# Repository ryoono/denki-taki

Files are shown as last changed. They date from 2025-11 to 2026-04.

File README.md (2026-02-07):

# denki-taki

## 要求仕様
[要求仕様](./docs/requirement.md)は別資料にまとめる。  

## ソフトウェア設計

```mermaid
flowchart TD
  %% =========================
  %% System Overview
  %% =========================
  subgraph SYS[Main loop control / non blocking]
    NOW[millis -> now]
    DOUT[D6 D7 pulse scheduler]
    CANDLE[LED flicker scheduler]
  end

  NOW --> DOUT
  NOW --> CANDLE

  %% =========================
  %% LED Flicker PWM D5 D9
  %% =========================
  subgraph PWM[LED flicker PWM on D5 D9]
    SCH[nextUpdateMs gate]
    FOLD[Folded quadratic mapping\nvalue update]
    EDGE[Edge re injection\nrandom reset near limits]
    PHASE[Opposite phase mapping\nvalue_1 value_2]
    CLAMP[Clamp 0 to 255]
    GAMMA[Gamma correction\ngamma8 table]
    WRITE[Write PWM duty\nwriteCh1 writeCh2]
    JIT[Jitter dt\nnextUpdateMs update]
  end

  CANDLE --> SCH
  SCH -->|now >= nextUpdateMs| FOLD
  FOLD --> EDGE
  EDGE --> PHASE
  PHASE --> CLAMP
  CLAMP --> GAMMA
  GAMMA --> WRITE
  WRITE --> JIT
  JIT --> SCH

  %% =========================
  %% Hardware PWM mapping
  %% =========================
  subgraph HW_PWM[Hardware PWM mapping]
    MAP[map255ToT1\n0 to 255 -> 0 to 999]
    D5[D5 Timer3 OC3A\nOCR3A]
    D9[D9 Timer1 OC1A\nOCR1A]
    TOP[T1_TOP = 999\nprescaler 8]
  end

  WRITE --> MAP
  MAP --> D5
  MAP --> D9
  TOP --> MAP

  %% =========================
  %% Digital output scheduling
  %% =========================
  subgraph DOUT_SM[D6 D7 digital pulse control]
    RND[randWaitMs\n500 to 10000 ms]
    D6SM[D6 state machine]
    D7SM[D7 state machine\nblock overlap]
  end

  DOUT --> DOUT_SM
  RND --> D6SM
  RND --> D7SM

  %% D6 state machine
  subgraph D6STATE[D6 state]
    D6WAIT[WAIT\nnow < d6NextMs]
    D6ON[ON 40 ms\nnow < d6OffMs]
    D6OFF[OFF\nschedule next]
  end

  D6SM --> D6WAIT
  D6WAIT -->|timeout| D6ON
  D6ON -->|40 ms elapsed| D6OFF
  D6OFF -->|set next wait| D6WAIT

  %% D7 state machine
  subgraph D7STATE[D7 state]
    D7WAIT[WAIT\nnow < d7NextMs]
    D7CHECK[Check overlap\nwith D6]
    D7DEFER[Defer\nwait for D6 OFF]
    D7ON[ON 40 ms\nnow < d7OffMs]
    D7OFF[OFF\nschedule next]
  end

  D7SM --> D7WAIT
  D7WAIT -->|timeout| D7CHECK
  D7CHECK -->|D6 ON| D7DEFER
  D7DEFER --> D7WAIT
  D7CHECK -->|D6 OFF| D7ON
  D7ON -->|40 ms elapsed| D7OFF
  D7OFF -->|set next wait| D7WAIT

  %% =========================
  %% Pin usage summary
  %% =========================
  subgraph IO[Pin usage D2 to D9]
    P2[D2 free]
    P3[D3 free]
    P4[D4 free]
    P5[D5 PWM CH1]
    P6[D6 digital pulse]
    P7[D7 digital pulse blocked]
    P8[D8 free]
    P9[D9 PWM CH2]
  end

  D6ON --> P6
  D7ON --> P7
  D5 --> P5
  D9 --> P9
```

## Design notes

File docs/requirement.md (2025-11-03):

本資料は「電気TAKI-焚-」要求仕様に関してまとめる。  

# 🔥 電気焚火キャンドル ― 設計思想（要約）

焚き火の魅力は「同じ瞬間が二度とない」こと。  
本作品はその偶然性と癒しを、電子制御ではなく**物理現象**によって再現する。  
ソレノイドが実際に空気を震わせ、吊り板が微妙に揺らぐ。  
その**わずかな誤差や乱れ**が、電子機器に“一期一会”の**わびさび**を与える。  
焚き火や焚き火キャンドルは火を用いるため扱いに注意が必要だが、本デバイスは電気で動作するため、安全性が高い。  

# 🔥 5W1H概要

| 要素 | 内容 |
|---|---|
| **Who（誰が）** | 室内で火を使えない人々（マンション・学生寮・家庭内など）や、就寝前に落ち着いた時間を過ごしたい人。 |
| **What（何を）** | 焚き火キャンドルのような**穏やかな炎の光と“パチパチ音”**を、火を使わずに再現する**リラックス用インテリアデバイス**。LEDの炎表現と、ソレノイドによる物理音が組み合わされた“電気焚火”。 |
| **When（いつ）** | 就寝前や読書・休憩・瞑想時など、**静かな夜のリラックスタイム**。長時間の点灯や寝落ちも想定し、安全性を重視。 |
| **Where（どこで）** | **室内（寝室・書斎・リビング）** など、火気厳禁かつ静音性を求める空間。小型設計で机上・ベッドサイドなどに設置可能。 |
| **Why（なぜ）** | 既製の電気焚火は「スピーカーからの擬似音が人工的」という課題がある。<br>本作品では、**ソレノイドが物理的に音を鳴らす**ことで、より**自然で偶然性のある“生きた音”**を再現する。<br>火の危険を排除し、現代生活に適した“安全な焚き火体験”を提供する。 |
| **How（どのように）** | - **LEDの揺らぎ**で炎を再現（オレンジ＋温白、帽子型拡散カバーで柔らかい光）<br>- **吊り板（木製・プラスチック製）をソレノイドで叩く**ことで“パチッ”“コツッ”と自然な破裂音を生成<br>- 板が揺れるたびに**当たり所が変わるため、同じ音は二度と鳴らない**<br>- 熱や煙を出さず、**安全で長時間使用可能**<br>- **ネットワーク接続機能**を持ち、Webページ経由で設定を行う（物理ボタンを排除） |

# 🔥 要求仕様書

## 1. 機能要求（Functional Requirements）

| ID | 要求項目 | 要求内容 |
|----|---|---|
| FR-1 | 炎の表現機能 | LEDの明滅により、焚き火キャンドルの炎を模した**穏やかな光のゆらぎ**を表現する。光源は複数色LED（オレンジ・温白など）を用いる。 |
| FR-2 | 音の生成機能 | ソレノイドの機械的打撃によって、焚き火の「パチッ」「コツッ」という**物理的な破裂音**を生成する。スピーカーは使用しない。 |
| FR-3 | ランダム性の再現 | 吊り板（木・プラスチック）が揺れ、**打撃の当たり所が毎回異なる**ように設計する。電子的なノイズ生成ではなく、機械的偶然性で音の多様性を生む。 |
| FR-4 | 光と音の調和 | LEDのゆらぎとソレノイドの発音が**全体として焚き火のテンポ感**を再現する。不自然な連打や長無音が発生しない。 |
| FR-5 | 安全動作 | 火災・感電・過熱などの危険がない構造とし、安全な低電圧電源で動作する。 |
| FR-6 | 操作性 | 本体に複数の物理スイッチを設けず、**最小限の電源スイッチまたは無操作起動**を基本とする。 |
| FR-7 | 自動停止機能 | 一定時間後に自動消灯・休止を行い、寝落ち時でも安全に使用できる。 |
| FR-8 | ネットワーク設定・制御機能 | 自宅のネットワークに接続し、**Webブラウザから設定や操作ができる**こと。<br>・自動停止時間や光の明るさをWebページ上で変更可能。<br>・Wi-Fi設定はプログラム直書きでよい。<br>・本体外観のスタイリッシュさを優先するため、ボタンや表示を極力省略する。 |

---

## 2. 非機能要求（Non-Functional Requirements）

| ID | 要求項目 | 要求内容 |
|----|---|---|
| NFR-1 | 静音性 | 音は就寝環境で心地よく感じられる程度とし、不快なノイズや過大な衝撃音を発生させない。 |
| NFR-2 | 音質 | 音は乾いた破裂音として自然に聴こえること。余韻やこもりを感じさせないこと。 |
| NFR-3 | 光の質感 | LED光は柔らかく、直視しても眩しくない。帽子型拡散カバーで穏やかに。 |
| NFR-4 | 審美性 | **ボタンや表示を極力排除**し、シンプルで静かな外観とする。配線は背面にまとめ、生活空間に溶け込むデザインとする。 |
| NFR-5 | 耐久性 | 通常の使用環境下で、打撃や吊り構造の破損・絡みが生じない。 |
| NFR-6 | メンテナンス性 | 構造を簡素にし、吊り板・糸・チップなどの交換を容易に行える。 |
| NFR-7 | 信頼性 | 長時間運転しても誤作動や過熱が発生しない。 |
| NFR-8 | 感性価値 | 同じ音が二度と鳴らない「偶然性」を体験価値として設計に組み込む。 |
| NFR-9 | ネットワーク操作性 | 設定画面はスマートフォンやPCのブラウザから簡単に操作できること。特別なアプリを不要とし、操作の反応が快適であること。 |

---

## 3. 制約条件（Constraints）

| ID | 制約項目 | 内容 |
|----|---|---|
| C-1 | 火気・煙 | 火炎・煙・香料などを一切発生させない。 |
| C-2 | 電源 | **安全な低電圧電源**で動作させる。給電方式（AC / DC / USB等）は問わない。 |
| C-3 | 筐体寸法 | デスクやベッドサイドに設置可能な小型サイズとする。 |
| C-4 | 環境条件 | 一般的な室内環境で安定して動作すること。 |
| C-5 | 騒音制限 | ソレノイドの駆動音や筐体の共振が不快にならないよう防振構造を採用する。 |
| C-6 | 安全規格 | ショート・逆接・過熱・絶縁不良が起きない構造とする。 |
| C-7 | 製作制約 | 入手容易な電子部品・素材を使用し、特殊加工を必要としない。 |
| C-8 | ネットワーク | ネットワーク設定値（SSID・パスワード）はプログラム内に固定で保持する。通信は家庭内ネットワーク内で完結する。 |

---

## 4. プロジェクト条件（Project Conditions）

| 項目 | 内容 |
|---|---|
| 開発目的 | **第13回ソレコン（タカハソレノイドコンテスト）** への出展。<br>「癒し × ソレノイド × 電気表現」をテーマとした作品として提出。 |
| 納期 | **2026年2月16日（月）までにデバイス完成および提出動画の作成・提出を完了する。** |
| マイルストーン | <br>**2025年12月中**：ハードウェア設計・部品選定完了。<br>**2026年1月中旬**：ソレノイド・LED動作試作完了。<br>**2026年1月末**：ネットワーク機能統合・筐体設計完了。<br>**2026年2月前半**：デモ撮影・編集・提出準備。 |
| 成果物 | - 動作デモ動画（作品紹介＋構造説明）<br>- 実機（展示用）<br>- 本要求仕様書（GitHubにて公開・管理） |

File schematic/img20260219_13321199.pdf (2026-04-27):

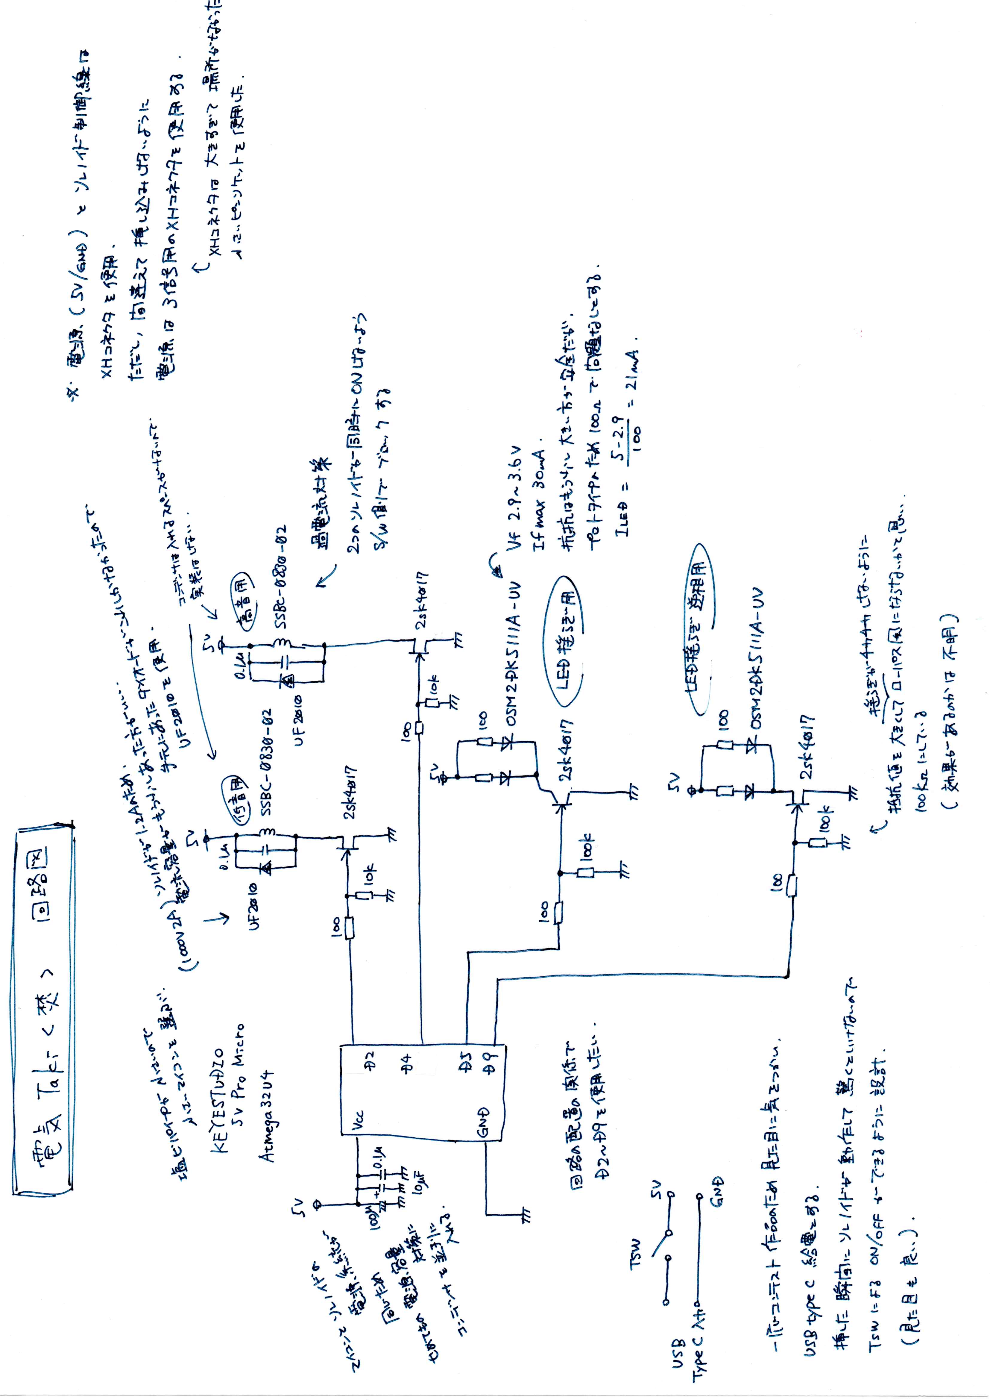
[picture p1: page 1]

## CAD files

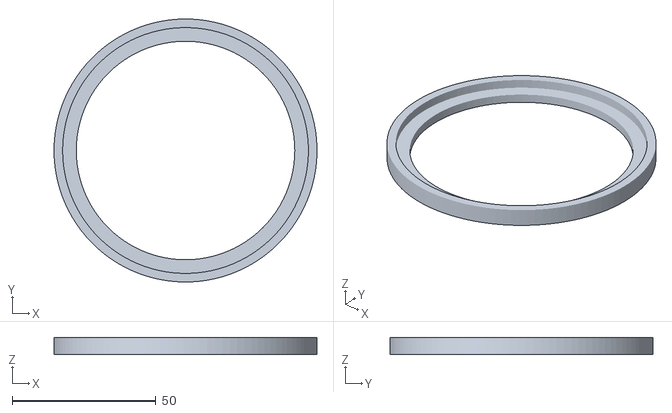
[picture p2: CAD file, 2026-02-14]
3d_data/キャンドルカバー.stl
91.5 x 91.5 x 6.00

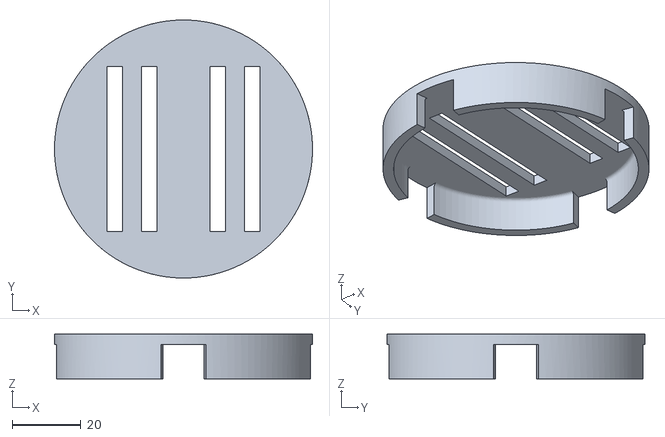
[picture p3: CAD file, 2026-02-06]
3d_data/ソレノイド固定台.stl
75.0 x 75.0 x 13.0

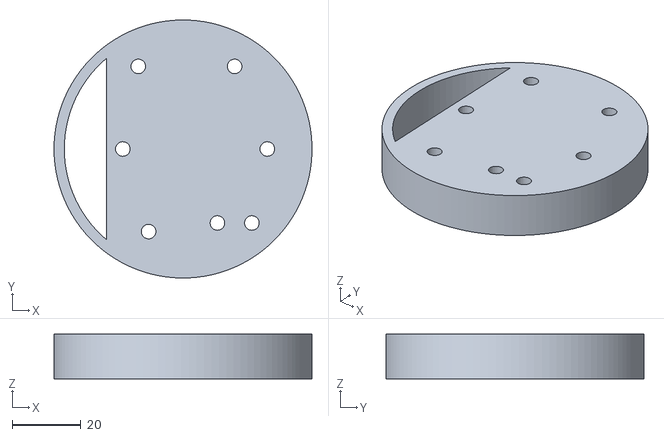
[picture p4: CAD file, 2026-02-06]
3d_data/マイコン固定台.stl
75.0 x 75.0 x 13.0

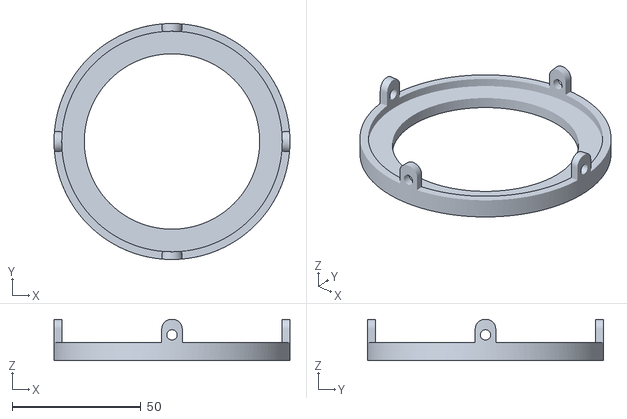
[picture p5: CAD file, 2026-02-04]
3d_data/塩ビパイプ_土台.stl
91.5 x 91.5 x 16.0

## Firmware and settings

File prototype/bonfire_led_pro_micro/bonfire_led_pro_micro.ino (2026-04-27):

/*
 * ボード：Amazonで購入した「KEYESTUDIO 5V Pro Micro Atmega32U4」
 * コンパイル時のボード設定：Arduino Leonardo
 * 
 * LEDの揺らぎ表現は、以下のWeb記事で紹介されている手法を元に実装している。
 * アルゴリズム自体はオリジナルではなく、実装方法を参考にしている。
 * https://www.creativity-ape.com/entry/2020/12/16/232928
 * 
 * ソレノイドはランダム時間ごとに駆動する。
 * ただし、過電流を防ぐため片方ずつしか駆動しないようソフトウェアでブロックしている。
 * 
 * D5：
 *   LED揺らぎ用PWM出力（CH1）
 *   - Timer3 / OC3A
 *   - Fast PWM（TOP=999, prescaler=8）
 *   - gamma補正後のdutyを出力
 * 
 * D9：
 *   LED揺らぎ用PWM出力（CH2）
 *   - Timer1 / OC1A
 *   - Fast PWM（TOP=999, prescaler=8）
 *   - D5と逆位相の揺らぎ表現
 * 
 * D2：
 *   デジタル出力（パルス制御）破裂音担当
 *   - 0～30000msのランダム待ち時間後にON
 *   - ON時間は40ms固定
 *   - 過電流防止のため、D4と同時ONしない
 * 
 * D4：
 *   デジタル出力（パルス制御）折れ音担当
 *   - 0～20000msのランダム待ち時間後にON
 *   - ON時間は40ms固定
 *   - D2がON中の場合は、D2がOFFになるまでONを待機
*/

#include <Arduino.h>
#include <avr/pgmspace.h>

// ---- Gamma table ----
// 人間の目の明るさ感覚に合わせるための gamma 補正テーブル
// 0–255 の duty 値を、見た目が自然になるように変換する
const uint8_t PROGMEM gamma8[] = {
  0, 0, 0, 0, 0, 0, 0, 0, 0, 0, 0, 0, 0, 0, 0, 0,
  0, 0, 0, 0, 0, 0, 0, 0, 0, 0, 0, 0, 1, 1, 1, 1,
  1, 1, 1, 1, 1, 1, 1, 1, 1, 2, 2, 2, 2, 2, 2, 2,
  2, 3, 3, 3, 3, 3, 3, 3, 4, 4, 4, 4, 4, 5, 5, 5,
  5, 6, 6, 6, 6, 7, 7, 7, 7, 8, 8, 8, 9, 9, 9, 10,
  10, 10, 11, 11, 11, 12, 12, 13, 13, 13, 14, 14, 15, 15, 16, 16,
  17, 17, 18, 18, 19, 19, 20, 20, 21, 21, 22, 22, 23, 24, 24, 25,
  25, 26, 27, 27, 28, 29, 29, 30, 31, 32, 32, 33, 34, 35, 35, 36,
  37, 38, 39, 39, 40, 41, 42, 43, 44, 45, 46, 47, 48, 49, 50, 50,
  51, 52, 54, 55, 56, 57, 58, 59, 60, 61, 62, 63, 64, 66, 67, 68,
  69, 70, 72, 73, 74, 75, 77, 78, 79, 81, 82, 83, 85, 86, 87, 89,
  90, 92, 93, 95, 96, 98, 99, 101, 102, 104, 105, 107, 109, 110, 112, 114,
  115, 117, 119, 120, 122, 124, 126, 127, 129, 131, 133, 135, 137, 138, 140, 142,
  144, 146, 148, 150, 152, 154, 156, 158, 160, 162, 164, 167, 169, 171, 173, 175,
  177, 180, 182, 184, 186, 189, 191, 193, 196, 198, 200, 203, 205, 208, 210, 213,
  215, 218, 220, 223, 225, 228, 231, 233, 236, 239, 241, 244, 247, 249, 252, 255
};

// ---- PWM pins ----
// PWM出力に使用するピン
// D5 : Timer3 / OC3A
// D9 : Timer1 / OC1A
static const uint8_t LED_PIN_1 = 5; // D5  (Timer3 OC3A)
static const uint8_t LED_PIN_2 = 9; // D9  (Timer1 OC1A)

// ---- Digital output pins ----
// 単純な digital output 用ピン（PWMは使わない）
static const uint8_t DOUT_PIN_2 = 2; // D2
static const uint8_t DOUT_PIN_4 = 4; // D4

// ---- Digital output timing parameters ----
// デジタル出力のON時間と待ち時間の条件
static const uint16_t DOUT_ON_MS        = 20;     // ONする時間 [ms]
static const uint16_t DOUT_WAIT_MINMS   = 500;    // 待ち時間の最小値 [ms]）
static const uint16_t DOUT2_WAIT_MAXMS  = 3500;  // 待ち時間の最大値 [ms]（D2: 破裂音）
static const uint16_t DOUT4_WAIT_MAXMS  = 3000;  // 待ち時間の最大値 [ms]（D4: 折れ音）

// ---- Digital output states ----
// D2 / D4 それぞれの状態管理用変数
static uint32_t d2NextMs = 0;
static uint32_t d2OffMs  = 0;
static bool     d2On     = false;

static uint32_t d4NextMs = 0;
static uint32_t d4OffMs  = 0;
static bool     d4On     = false;

// 待ち時間をランダムに生成するヘルパ関数
static inline uint16_t randWaitMsD2() {
  return (uint16_t)random( DOUT_WAIT_MINMS, (long)DOUT2_WAIT_MAXMS + 1L);
}
static inline uint16_t randWaitMsD4() {
  return (uint16_t)random( DOUT_WAIT_MINMS, (long)DOUT4_WAIT_MAXMS + 1L);
}

// ---- Candle parameters ----
// 揺らぎ計算用の内部状態
static float value = 0.10f;

static const int   max_value     = 255;
static const int   dimming_range = 50;   // 値を大きくするとコントラストが強くなる
static const float threshold     = 0.065f;

uint8_t duty1 = 0;
uint8_t duty2 = 0;

// 揺らぎ更新タイミング管理用
static uint32_t nextUpdateMs = 0;

// 電源投入時のフェードイン制御用
static uint32_t bootMs = 0;

// ---- Timer1 settings ----
// Timer1 を使って PWM 周波数を正確に設定する
// prescaler = 8
// TOP = 999 → 約2kHz
static const uint16_t T1_TOP = 999;

// gamma 補正後の 0–255 を Timer1 用のカウント値に変換
static inline uint16_t map255ToT1(uint8_t d) {
  return (uint32_t)d * T1_TOP / 255u;
}

// ---- Setup PWM on D5 (Timer3) ----
// Timer3 を使った PWM 出力設定
static void setupTimer2PwmOnD3() {
  pinMode(LED_PIN_1, OUTPUT);

  TCCR3A = 0;
  TCCR3B = 0;

  // Fast PWM, TOP = ICR3
  TCCR3A |= (1 << WGM31);
  TCCR3B |= (1 << WGM33) | (1 << WGM32);

  // Non-inverting mode on OC3A
  TCCR3A |= (1 << COM3A1);

  // prescaler = 8
  TCCR3B |= (1 << CS31);

  ICR3  = T1_TOP;
  OCR3A = 0;
}

// ---- Setup PWM on D9 (Timer1) ----
// Timer1 を使った PWM 出力設定
static void setupTimer1PwmOnD9() {
  pinMode(LED_PIN_2, OUTPUT);

  TCCR1A = 0;
  TCCR1B = 0;

  // Fast PWM, TOP = ICR1
  TCCR1A |= (1 << WGM11);
  TCCR1B |= (1 << WGM13) | (1 << WGM12);

  // Non-inverting mode on OC1A
  TCCR1A |= (1 << COM1A1);

  // prescaler = 8
  TCCR1B |= (1 << CS11);

  ICR1  = T1_TOP;
  OCR1A = 0;
}

// PWM duty 更新（D5）
static inline void writeCh1(uint8_t duty255) {
  OCR3A = map255ToT1(duty255);
}

// PWM duty 更新（D9）
static inline void writeCh2(uint8_t duty255) {
  OCR1A = map255ToT1(duty255);
}

void setup() {
  setupTimer2PwmOnD3();
  setupTimer1PwmOnD9();

  pinMode(DOUT_PIN_2, OUTPUT);
  pinMode(DOUT_PIN_4, OUTPUT);
  digitalWrite(DOUT_PIN_2, LOW);
  digitalWrite(DOUT_PIN_4, LOW);

  // A0 を使って乱数の初期化（未接続前提）
  randomSeed(analogRead(A0));
  nextUpdateMs = millis();
  bootMs = nextUpdateMs;

  // 起動直後に1回だけ duty を確定させる（未初期化/不定値の防止）
  int value_1 = max_value - dimming_range + (int)(value * dimming_range);
  int value_2 = max_value - (int)(value * dimming_range);

  if (value_1 < 0) value_1 = 0; if (value_1 > 255) value_1 = 255;
  if (value_2 < 0) value_2 = 0; if (value_2 > 255) value_2 = 255;

  duty1 = pgm_read_byte(&(gamma8[value_1]));
  duty2 = pgm_read_byte(&(gamma8[value_2]));

  d2NextMs = nextUpdateMs + (uint32_t)randWaitMsD2();
  d4NextMs = nextUpdateMs + (uint32_t)randWaitMsD4();
}

void loop() {
  uint32_t now = millis();

  // ---- D2 control ----
  // ランダム時間待ち → 40msだけON（破裂音）
  if (d2On) {
    if ((int32_t)(now - d2OffMs) >= 0) {
      digitalWrite(DOUT_PIN_2, LOW);
      d2On = false;
      d2NextMs = now + (uint32_t)randWaitMsD2();
    }
  } else {
    if ((int32_t)(now - d2NextMs) >= 0) {
      digitalWrite(DOUT_PIN_2, HIGH);
      d2On = true;
      d2OffMs = now + (uint32_t)DOUT_ON_MS;
    }
  }

  // ---- D4 control ----
  // D2 と同時に ON しないようにソフトウェアでブロックする（折れ音）
  if (d4On) {
    if ((int32_t)(now - d4OffMs) >= 0) {
      digitalWrite(DOUT_PIN_4, LOW);
      d4On = false;
      d4NextMs = now + (uint32_t)randWaitMsD4();
    }
  } else {
    if ((int32_t)(now - d4NextMs) >= 0) {
      if (d2On) {
        d4NextMs = d2OffMs;
      } else {
        digitalWrite(DOUT_PIN_4, HIGH);
        d4On = true;
        d4OffMs = now + (uint32_t)DOUT_ON_MS;
      }
    }
  }

  if (!((int32_t)(now - nextUpdateMs) < 0)){

    // ---- 揺らぎ計算 ----
    if (value < 0.5f) {
      value = value + 2.0f * value * value;
    } else {
      float t = 1.0f - value;
      value = value - 2.0f * t * t;
    }

    // 周期性を壊すため、端に来たら値を再注入
    if (value <= (0.0f + threshold) || (1.0f - threshold) <= value) {
      long r = random((long)(threshold * 1000.0f), (long)(1000.0f - threshold * 1000.0f));
      value = (float)r / 1000.0f;
    }

    // 2チャンネルを逆位相で駆動
    int value_1 = max_value - dimming_range + (int)(value * dimming_range);
    int value_2 = max_value - (int)(value * dimming_range);

    if (value_1 < 0) value_1 = 0; if (value_1 > 255) value_1 = 255;
    if (value_2 < 0) value_2 = 0; if (value_2 > 255) value_2 = 255;

    duty1 = pgm_read_byte(&(gamma8[value_1]));
    duty2 = pgm_read_byte(&(gamma8[value_2]));

    // 次回更新タイミングをランダムにずらす
    uint16_t dt = 80 + (uint16_t)random(0, 46);
    if (random(0, 3) == 0) {
      dt += (uint16_t)random(40, 140);
    }
    nextUpdateMs = now + dt;
  }

  // 電源投入時のみ、約2秒かけてゆっくりと光らせる（揺らぎは維持してスケールする）
  uint32_t elapsed = now - bootMs;
  if (elapsed < 2048UL) {
    // int16_tで計算してしまい、桁あふれしてしまっていた
    uint8_t duty1_buf = (uint8_t)(((uint32_t)duty1 * (uint32_t)elapsed) >> 11 );
    uint8_t duty2_buf = (uint8_t)(((uint32_t)duty2 * (uint32_t)elapsed) >> 11 );
    writeCh1(duty1_buf);
    writeCh2(duty2_buf);
  }
  else{
    writeCh1(duty1);
    writeCh2(duty2);
  }
}

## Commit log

2025-11-03 要求仕様追加
2026-02-04 ゆらぎのプログラム格納
2026-02-04 3Dモデル格納
    [ソレノイド固定台.stl, 塩ビパイプ_土台.stl]
2026-02-06 固定台追加
    [ソレノイド固定台.stl, マイコン固定台.stl]
2026-02-07 フローチャート追加
2026-02-07 サイズの問題でマイコンを変更
2026-02-14 キャンドルカバー追加
    [キャンドルカバー.stl]
2026-02-14 ピンアサインの修正
2026-04-27 現物合わせ
2026-04-27 回路図の追加
